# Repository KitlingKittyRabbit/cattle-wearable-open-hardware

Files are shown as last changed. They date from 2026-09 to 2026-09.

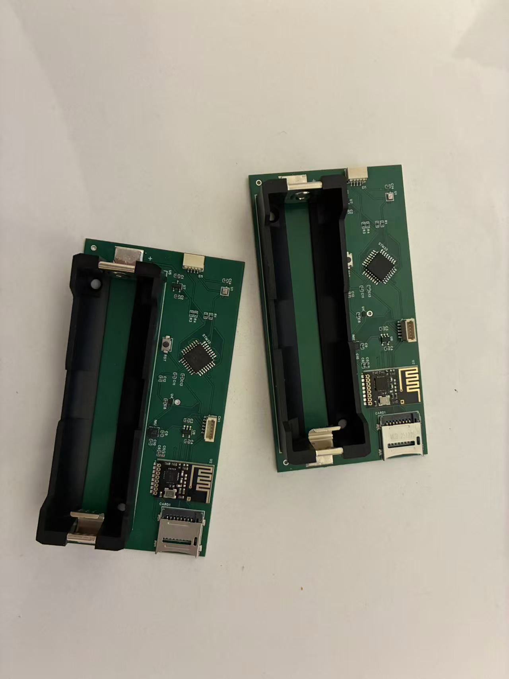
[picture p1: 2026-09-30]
项目文档/图片/实物图.jpg

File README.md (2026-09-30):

# Cattle Wearable Research Platform

An open hardware and firmware prototype for long-duration monitoring of dairy
cows during the transition period. The device combines motion, pressure,
temperature, storage, and low-rate radio telemetry in a belt-mounted enclosure.

This repository documents a research prototype. It does not claim validated
disease prediction, veterinary effectiveness, animal-safety certification, or
production readiness.

## Research scope

The long-term research goal is to investigate whether wearable signals can
support early warning of periparturient disease. Behavior recognition and
respiratory measurements are intermediate capabilities, not established
clinical outcomes. Short farm trials and video alignment are engineering
pretests rather than evidence of diagnostic performance.

## Hardware overview

| Component | Role |
| --- | --- |
| STM32G030K8T6 | Main microcontroller |
| QMI8658A | Six-axis motion sensing |
| GZP pressure sensor | Pneumatic respiratory signal |
| ICP-20100 | Pressure-assisted posture transitions |
| MTS4 | Surface-temperature sensing |
| SD card | Primary sensor-data storage |
| NF-03 radio | Low-rate health heartbeat only |
| OLED | Startup diagnostics only |

The NF-03 link intentionally carries device-health heartbeats rather than the
sensor stream. Full-rate measurements remain on the SD card.

## Repository layout

```text
3D打印模型/        Editable FreeCAD models and STL exports
原理图/            Exported schematic
硬件资料/          Bill of materials
固件/              Bare-metal STM32 firmware and linker script
工具/              Log conversion, radio monitoring, and regression tests
项目文档/          Validation plans and evidence templates
```

Directory names are retained from the original engineering workspace so that
existing build and validation scripts remain traceable.

Slicer project files are intentionally omitted from the public release because
they can embed local printer profiles and account identifiers. Generate a new
print project from the included CAD or STL source for your own printer.

## Firmware build

Install the Arm GNU toolchain and run:

```bash
make -C 固件
```

The output is written to `固件/编译输出/`, which is ignored by Git.

## Data conversion

The current binary log format is V4. Historical V1–V3 frames remain readable.

```bash
python3 工具/bin2csv.py INPUT.bin OUTPUT.csv
```

The logger records timestamp validity, sensor status, storage status, and
sampling diagnostics. A successful conversion does not establish sensor
accuracy; calibration and field validation are separate requirements.

## Radio heartbeat monitor

The 32-byte V3 heartbeat contains a device identifier, sequence number,
monotonic uptime, sensor status, and SD-card status. Each logical heartbeat is
broadcast three times; the receiver records every physical packet and marks
duplicates instead of discarding them.

```bash
python3 工具/nf04_monitor.py
```

Use `--port` to preselect a serial port and `--csv` to choose the append-only
CSV log. Local CSV and JSONL runtime outputs are excluded from Git.

## Validation status

- firmware timing and binary-log parsing have host-side regression tests;
- the CAD enclosure and belt fixtures are included as editable sources;
- the schematic is currently provided as an exported PDF;
- PCB source, manufacturing outputs, and complete assembly instructions are not
  yet included;
- animal fit, durability, battery life, measurement validity, and welfare must
  be evaluated before field deployment.

For detailed historical engineering notes in Chinese, see
[`docs/README.zh-CN.md`](docs/README.zh-CN.md).

## Licensing

- software and firmware: Apache-2.0;
- original mechanical and hardware design files: CERN-OHL-P-2.0;
- original documentation and photographs: CC-BY-4.0.

See [LICENSES.md](LICENSES.md). Component names and third-party specifications
remain the property of their respective owners.

## Animal welfare and safety

Any animal study should receive the approvals required by the relevant
institution and jurisdiction. Independently assess fit, skin contact, pressure,
thermal behavior, battery protection, water ingress, entanglement, and emergency
removal. Do not use this prototype for veterinary decisions without appropriate
validation and professional oversight.

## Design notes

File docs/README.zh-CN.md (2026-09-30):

# 牛腰带 PCB32

奶牛围产期可穿戴监测腰带（PCB32 版本）。

## 研究定位与边界

### 已确认事实

本项目的研究主目标是实现奶牛围产期疾病预警系统，但不保证一定成功。如果目标牛场的病牛样本不足，或者现有数据无法支撑疾病预警，就需要转向备选研究问题；节律研究只是可能方向之一，当前备选路线尚未确定。行为识别是服务于预警的中间能力，不是最终研究目的。

腰带与项圈的主体监测功能相同；腰带相比项圈只多一个气囊，用于呼吸测量。

### 传感器与部件职责（已确认）

| 部件 | 直接职责 |
| --- | --- |
| QMI8658A | 提供运动数据，为行为识别提供输入 |
| GZP | 测量气囊压力变化，目标是获取呼吸信息 |
| ICP-20100 | 辅助识别起卧 |
| MTS4 | 测量体表温度 |
| SD | 保存正式传感器数据 |
| NF-03 | 只发送低频心跳，不发送传感器数据；心跳用于证明设备仍正常工作并提供时间对齐锚点；在满足这两个目的的前提下，发送频率应尽可能低以节省功耗 |
| OLED | 仅用于首次启动后的短时自检，之后不参与正式运行 |

设备的预期生命周期是：首次启动完成自检后进入休眠，等待外部信号唤醒；唤醒后持续采集数据、记录数据并发送低频心跳；此后设备再次重启时不应重新进入首次休眠状态。这里记录的是设计意图，不声称当前固件已经实现上述全部生命周期或时间对齐设计。

牛场短时录像及可能进行的一周试戴属于预实验，用于确认佩戴、对时、连续记录和信号可用性，不是正式疾病预警有效性证据。

### 尚待讨论

以下事项尚未形成既定方案：变量构造、数据基本单位与时间语义、建模方法、具体疾病预警方法、备选研究路线、外部唤醒实现，以及 NF 与 SD/录像的具体对齐实现。

## 项目结构

```
.
├── 3D打印模型/
│   ├── 外壳/          # FreeCAD 外壳模型和指定打印模型
│   ├── 腰带扣合/      # 腰带扣合结构模型
│   └── 打印工程/      # Bambu Studio 打印工程
├── 原理图/            # 原理图 PDF
├── 硬件资料/
│   └── BOM_260530_PCB32_2026-06-09.csv   # 物料清单
├── 固件/              # STM32G030K8T6 裸机固件
│   ├── 源码/          # C 源码
│   ├── 链接脚本/      # 链接脚本
│   ├── 编译输出/      # 本地构建产物，不进入 Git
│   └── *.py / *.sh    # 传感器读取辅助脚本
├── 工具/              # 数据解析与测试脚本
│   ├── bin2csv.py     # 设备 BIN 日志转 CSV
│   ├── nf04_rx.py     # ESP32-C3 + NF-04 接收测试
│   ├── esp32_nf04_rx.ino # ESP32 接收端测试
│   ├── nf04_monitor.py # USB 串口心跳监控面板
│   └── nf04_protocol.py # 心跳编解码与 JSONL 定义
├── 项目文档/
│   ├── 图片/          # 实物照片等文档图片
│   └── 硬件验证/      # 真机验证计划、模板和证据目录
└── 归档/              # 本地历史资料，整体由 Git 忽略
```

## 硬件

- 主控：STM32G030K8T6 (ARM Cortex-M0+)
- IMU：QMI8658A（6 轴加速度/陀螺仪）
- 气压：ICP-20100、GZP 系列
- 温度：MTS4
- 无线：NF-03（2.4 GHz）
- 电源：BH-21700-B1BJ001（21700 电池座）

## 固件编译

```bash
make -C 固件
```

需要安装 ARM GCC 工具链：`arm-none-eabi-gcc`。

## NF-04 心跳与电脑监控

固件在传感器、SD 卡和日志创建完成后立即发送一次启动心跳（seq=0），随后
按运行时绝对 30 分钟网格发送（seq=1、2……），不会从每次发送完成后重新计时。
正式心跳周期固定为 `1800000 ms`（30 分钟）。真机首包和第二包验证、功耗测试
均直接使用这一套正式固件。

NF-04 心跳固定 32 字节，协议版本为 3，字段为：

| 字节 | 含义 |
| --- | --- |
| 0–2 | 构建/部署时配置的设备 ID（大端字节序显示） |
| 3 | 协议版本（V3） |
| 4 | 消息类型（1：心跳） |
| 5–8 | 心跳序号（大端 uint32） |
| 9–12 | 设备单调运行时间 ms（大端 uint32） |
| 13–16 | QMI、ICP、GZP、MTS4 状态 |
| 17 | SD 初始化成功 bit0、正在记录 bit1、SD 已满 bit2 |
| 18–31 | 保留，发送为 0 |

每个 30 分钟逻辑心跳使用同一序号发送三份单向广播：首份立即发送，后两份在
5–15 秒和 15–30 秒窗口内按设备 ID、序号和副本序号确定性分散。每份发送前
重新组装实际运行时间与传感器/SD 状态；不启用自动 ACK 或自动重试。MicroPython
与 Arduino 接收端都监听共同 RF 地址，并把每一份通过协议校验的物理报文逐条输出为稳定的
`NF04_HEARTBEAT {JSON}` 或 `NF04_ERROR {JSON}` 行。电脑端面板启动后可刷新并选择
接收端串口；也可以直接用 `--port` 预选，再运行：

```bash
python3 工具/nf04_monitor.py
# 高级用法：预选串口
python3 工具/nf04_monitor.py --port /dev/ttyACM0 --csv nf04-heartbeats.csv
```

面板按物理接收记录逐行显示在线/超时、电脑接收时间、序号、设备运行时间、四类
传感器状态和 SD/记录状态；同一设备同一序号的三份广播会各占一行，不会覆盖旧记录。
CSV 为每一份通过协议校验的心跳追加一行，并包含 `duplicate` 标记；它不是去重后的
逻辑摘要。面板还在 CSV 同目录追加保存 `nf04-monitor.log` JSONL：每一份实际报文
按电脑接收顺序写入一个 `heartbeat_raw` 事件，完整保留接收时间、设备 ID、协议版本/类型、
序号、运行时间、全部传感器状态、SD 初始化/记录活动/已满状态和 `duplicate: true/false`。
重复标记只用于说明副本关系和序号/统计诊断，不会丢弃、缩减、覆盖或改写任何原始接收记录。
面板中的“清空显示”只清除当前列表和错误提示，不删除、截断或覆盖 CSV/JSONL，清空后仍会
继续接收追加。面板重启或重新连接会继续使用同一文件；这些本机运行输出由 `.gitignore` 排除。
默认超时阈值为 32 分钟；可以用 `--timeout-seconds` 集中调整。未知协议版本、
损坏 JSON、串口断开均显示为错误，不会让面板退出。

启动首包和绝对周期推进由 `固件/源码/issue3_logic.h` 的共享 C 状态机定义，
固件与 `工具/test_issue3_logic.c` 直接复用；电脑端测试只验证协议、记录时间和
面板状态，不复制固件调度算法。

长期集成测试分开报告 SD 时序：正常成功读写模型（5 ms/5 ms）运行 4 小时，
GZP 原始计划 144000 次全部启动并读取，二分后 72000 个结果落盘，真实漏采为 0；
声明的 SD 读/写上界（29 ms/13 ms）
是故障压力边界，不是“采样通过”场景，测试会明确显示其真实漏采数量、重复数和
时间顺序，并验证漏采被计数且采集不会永久停滞。该压力结果不能替代真实 SD 卡长测。

正式采集期间，SD 的读响应/token、512 字节数据块、写响应和 busy 等待使用固件与
主机测试共用的可暂停状态机。SD 与 NF 共用 STM32G030 的 SPI1（PA5/PA6/PA7，AF0）：
SD 识别阶段使用 HSI16/PCLK÷64=250 kHz，完成首个扇区探测后切换到 PCLK÷8=2 MHz；
两条路径均由同一总线所有权和独立 CS 保护。每次最多推进 8 字节，硬件线上 4 us/字节，
连同寄存器轮询和 CS 开销按 8 us/字节设有界上限（单步最多 64 us）。步骤之间先服务
GZP、QMI 和 ICP；启动探测与日志创建发生在正式采集开始前，仍可使用同步初始化路径。
常规 120 ms 扇区写入场景因此要求 GZP 计划、启动、落盘逐点一致且 `missed=0`；
新的 29/13 ms SD 读/写声明上界只作为单独的不可承受压力诊断。
帧保留窗口仍额外保留 1.82 s 的卡内部 busy/元数据安全余量；这不是把旧软件
SPI 吞吐当作新的性能结论。
GZP 转换完成结果使用固定上限的共享小队列跨越短暂 SD/FAT 占用，结果满时才按
实际无法承受的计划网格计为漏采，不通过放宽迟到容限掩盖损失。

正式 BIN 日志当前为 V4：每秒帧大小 368 字节（CRC 位于偏移 364），QMI 槽位 16、
GZP 槽位 5、ICP 槽位 2、MTS4 槽位 1。QMI 仍以约 28.025 Hz 读取并推进原生 FIFO
时钟，GZP 仍按 100 ms 绝对计划网格转换和读取；二者只在成功读取之后由跨 FIFO/转换、
跨帧持久相位各保留连续两个原始项目中的一个；迟到仍在容限内时保留原网格时间，
超出迟到容限而启动当前转换时使用实际启动时间戳。
有意二分不计为 missed、drop、late 或 overflow；真实 I²C、转换、FIFO、队列和时间
窗口故障仍按原诊断报告。`工具/bin2csv.py` 同时保留 V1/V2/V3 历史日志解析。

QMI 运行期的停滞看门狗以“最后一次成功读取完整原始样本”的单调运行时间为唯一期限
基准，而不是只等待某一种 FIFO 状态：初始化后尚未成功读到第一批，或之后连续 500 ms
没有成功原始样本，且 100 ms QMI 服务仍在运行，就触发一次有界恢复。合法空 FIFO、
count/`FIFO_STATUS` 矛盾、非空 FIFO 的 CTRL9/FIFO_DATA/cleanup 失败都会留在这条
无成功样本计时路径；单次瞬态错误不会立即重复重置。恢复退出读模式、RST_FIFO、重写并
读回当前 CTRL1/2/3/6/7/8、水位和 FIFO_CTRL，再独立读回 count LSB/status，核验 count=0、
`NOT_EMPTY/WTM/FULL/OVERFLOW` 全部清零及 `FIFO_RD_MODE=0`，失败后至少 1 s 才重试。
每次停滞恢复尝试写入 V4 状态位 10（兼容旧名称 `qmi_empty_recovery`），成功/失败分别
按事件累计 OR 写入位 11/12；无论寄存器恢复成败，旧 QMI 时钟都会失效，下一批成功原始
样本按当前时间重新锚定。`bin2csv.py` 输出这三个可读状态列，历史 V1/V2/V3 帧按零值
兼容解析。

即使 FIFO_DATA 每次都成功，运行期每个合法非空批次仍会用
`batch_now_us - (samples - 1) * ISSUE3_QMI_SAMPLE_PERIOD_US` 计算当前采样窗口；若旧软件
时钟落后该窗口超过 500 ms，则在读取样本前前移重锚并保留 `qmi_reanchors`/重新锚定状态。
小于该阈值的 100 ms 调度抖动继续沿用原时钟，不会每批重锚；批次锚点保证最后一个样本时间
不晚于本次读取时刻且输出时间单调。该校正独立于“500 ms 无成功原始样本”恢复看门狗。

QMI 的正式 FIFO 服务在确认有合法完整样本后直接进入读模式，逐个读取整个批次；某个
保留样本若落到 TIME、SD-owned OWNER 或 QUEUE 阻塞，只丢弃并记录该样本，不能拒绝
同批次后续样本，也不会因此复位 FIFO 或重新锚定。GZP 服务轻微迟到时仍启动当前网格
点；若已经越过多个网格，则只把已经完整错过的历史点计为 missed，最多启动一个当前
转换，并在超过迟到容限时用实际启动时间作为结果时间戳，下一截止点仍回到未来的绝对
100 ms 网格，不背靠背补做历史转换。

### 实机 SD 瓶颈定位诊断（本轮新增）

正式固件包含一个只驻留 RAM、不会写入 SD 或发送到 NF 的诊断区：
`volatile Issue3RuntimeDiagnostics r_issue3_diag`。正式运行开始后其首字段应为
`magic=0x49534433`、`version=1`；启动探测不会混入计数。结构记录主循环和
`sd_async_step()` 进度、同一活动事务内相邻 step 的最大间隔、扇区完成间隔、持久化字节和完整帧数、帧队列与
GZP 结果队列峰值、QMI/GZP/ICP 接收与入帧数，以及按队列/时间窗口/物理槽所有权
分类的丢弃数。

`sd_step_max_gap_ms` 只在同一尚未结束的 SD 事务中比较相邻两次
`sd_async_step()`；事务完成后会清除活动身份，因此两个独立事务之间的正常空闲不会
污染该字段。事务、step、阶段、扇区完成、FAT 预取/簇链接/metadata 和 TIME/OWNER/QUEUE
丢弃分类均通过 `固件/源码/issue3_logic.h` 的共享状态入口更新，主机诊断测试与正式
`main.c` 使用同一转换逻辑。

帧丢弃分类来自实际 frame-open 结果：TIME 表示时间戳早于可恢复窗口或落入不可恢复
时间孔洞，OWNER 仅表示该时间戳实际命中的物理槽由 SD pending 持有，QUEUE 表示需要
新开/补开帧但容量或其他队列条件阻塞；不会再以“存在任意 pending 槽”推断 OWNER。

SD 部分包括读/写/总事务数、每个完整事务的最近/累计/最大耗时、SPI 传输字节、
read-token 与 write-busy 轮询总数和单事务最大值、SPI 超时次数。`sd_transaction`
及 `sd_phase[0..6]` 的元素均为 `{entries,total_ms,last_ms,max_ms}`；阶段索引为：
`0 CMD`、`1 响应`、`2 读 token/写 token`、`3 读数据/读 CRC`、`4 写数据/写 CRC`、
`5 写响应`、`6 write-busy`。`total_ms` 为饱和的 32 位累计值，单次 `last_ms`/`max_ms`
为饱和的 16 位毫秒值（超过 65535 ms 会保留为 0xffff）。`fat_prefetch`、
`fat_link`、`metadata` 使用相同的四字段结构，分别对应 FAT 预取/分配、簇链接和
目录元数据逻辑操作。

Tiger 可在运行约两分钟后通过 ST-Link/GDB 一次读取完整结构（端口按现场 OpenOCD
配置替换）：

```text
arm-none-eabi-gdb 固件/编译输出/firmware.elf
(gdb) target extended-remote :4242
(gdb) monitor halt
(gdb) set print pretty on
(gdb) p/x r_issue3_diag
```

本诊断提交只用于区分 SPI 传输、卡 token/busy、FAT/元数据和前台推进间隔造成的
瓶颈，不表示吞吐问题已经修复；读取后请保留 magic/version 及全部字段原样记录。

正式主循环不会在每个 8 字节步骤后无条件执行 WFI：只要 SD/FAT、FIFO、待提交帧或
转换结果有可立即推进的工作，就继续服务传感器并推进下一步。QMI 保留 PB6/EXTI
快速路径，同时由 TIM3 每 100 ms 置独立的 FIFO/status 轮询标志；即使水位边沿漏掉，
仍会读取真实 FIFO level/status 并复用完整批次逐样本读取、溢出恢复和重新锚定逻辑。ICP 没有
中断线，由另一个独立的 100 ms 标志限频服务；SD 每个 8 字节步骤前先服务 QMI，再
服务到期 ICP，I²C 失败由下一轮继续重试，不把传感器停采变成前台忙轮询。GZP 约
20 ms、MTS4 约 50 ms 的转换完成期限使用 TIM3 比较唤醒；100 ms 更新中断负责较长期限，因此
WFI 不会把短转换拖到下一个 100 ms。日志还以完整数据扇区的实际完成时间作为进度
心跳；超过一个帧保留窗口加 5 秒仍有待写入工作却没有进度时，`log_active` 会清零，
避免心跳继续把写入停滞报告为正常记录。

主循环睡眠入口使用 `issue3_runtime_sleep_entry()`：先在关中断（PRIMASK）状态下重新
读取全部前台工作、软件到期标志和 TIM3/QMI 硬件 pending 位，再配置比较唤醒，执行
DSB/WFI，最后恢复中断。NF 的运行期短等待另使用同语义的
`issue3_atomic_wait_begin()`/`issue3_atomic_wait_step()`：新等待在同一关中断区内
关闭旧 CC1IE、清除上一轮 CC1IF、清零完成标志、读取 CNT、设置新的 CCR1 并启用
CC1IE；若配置期间计数跨过目标，则从新 CNT 重新建立目标。随后再在关中断后检查
`r_short_timer_done` 和 TIM3 pending，因此旧 pending 不会替代本次延迟，新事件仍会
保持 pending 并唤醒 WFI。Cortex-M0+ 在 PRIMASK 期间到达的 TIM3 比较、TIM3 更新或
QMI EXTI 会保持 pending 并唤醒 WFI，随后由 ISR 处理；比较配置不会清除刚到达的
pending 标志。`工具/test_issue3_logic.c` 和四小时异步测试直接调用共享入口，覆盖主
循环三种竞态、旧 CC1IF、计数回绕和配置前进，避免用独立的理想睡眠模型替代固件路径。

异步生产路径的四小时离散事件回归位于
`工具/test_issue3_async_long_capture.c`。它直接驱动 `Issue3SdTransfer`、
`Issue3SpiBus`、帧队列、QMI 逐样本 FIFO 服务、GZP/ICP 调度和 `Issue3LogPrefetch`，模拟
约 28.025 Hz QMI 原始读取、10 Hz GZP 原始转换、2 Hz ICP、30 分钟 MTS4、QMI EXTI 永不触发时的
100 ms 轮询兜底、ICP 100 ms 限频服务和非零 I²C 时间成本、V4 368 字节帧跨扇区和 FAT
跨簇链。运行期簇分配和旧簇到新簇的链接也逐步通过异步 FAT0/FAT1 扇区读写完成；
同步 FAT 访问只用于启动初始化和结束时的测试清理。SD 命令、token、数据和 busy
阶段之间继续推进传感器与 NF。测试以离散时间
运行四小时而不是等待现实四小时，最后从模拟卡的目录有效长度、FAT0/FAT1 链和实际
扇区字节反解析帧、CRC、样本唯一性和三副本心跳。主机上可用以下命令运行：

```bash
cc -std=c11 -O2 -Wall -Wextra -Werror -I固件/源码 \
  工具/test_issue3_async_long_capture.c -o /tmp/test_issue3_async_long_capture
/tmp/test_issue3_async_long_capture
```

NF-03 与 SD 共用硬件 SPI1 线，运行期由共用 C 所有权状态机互斥：SD 从命令开始直到
响应、数据、busy 完成并释放 CS 前，NF 只保留待发送副本，不访问 SPI；NF 发送、唤醒
和休眠期间也不会启动新的 SD 事务。心跳副本在总线释放后继续使用原序号和实际发送时刻
重新组包。主机回归覆盖 SD 命令、读 token、写数据和写 busy 阶段的到期心跳，并检查两
个 CS 从不同时有效。正常 120 ms 分步 SD 集成还持续产生 ICP 2 Hz 样本，样本经过 FIFO、
帧队列和模拟 SD 字节后按时间戳反解析，要求输入与落盘一一对应、无重复和漏采。

## 协作说明

- 本项目为私有仓库，仅供团队内部协作。
- 大文件（规格书 PDF、PPT、原始论文等）已归档到本地 `归档/`，不在 Git 中跟踪。
- 新增硬件资料请放到对应子目录；临时/个人文件不要提交。

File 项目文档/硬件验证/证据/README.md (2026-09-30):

# Validation evidence

This directory is reserved for small, reviewable hardware-test evidence, such
as:

- a short SD-card data sample used to validate `工具/bin2csv.py`;
- a short NF-03 receiver log demonstrating a physical radio packet;
- a necessary screenshot or compact text summary.

No physical-test sample or receiver log is included in the initial public
release. Add evidence only after a manual hardware test, and record its source,
date, firmware commit, and intended use in the corresponding validation record.

Do not commit long experiments, complete SD-card exports, private farm or animal
data, or large radio logs. Every evidence file must have a clear provenance and
data-sharing permission.

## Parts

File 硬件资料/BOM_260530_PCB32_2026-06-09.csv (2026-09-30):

No. | Quantity | Comment | Designator | Footprint | Value | Manufacturer Part | Manufacturer | Supplier Part | Supplier
1 | 4 | 1uF | C1,C2,C3,C4 | C0402 | 1uF | CL05A105KA5NQNC | SAMSUNG(三星) | C52923 | LCSC
2 | 2 | 10uF | C5,C12 | C0402 | 10uF | CL05A106MQ5NUNC | SAMSUNG(三星) | C15525 | LCSC
3 | 7 | 100nF | C6,C8,C9,C10,C11,C13,C14 | C0402 | 100nF | CL05B104KO5NNNC | SAMSUNG(三星) | C1525 | LCSC
4 | 1 | 472192001 | CARD1 | TF-SMD_472192001 |  | 472192001 | MOLEX | C164170 | LCSC
5 | 1 | ZX-SH1.0-5PLT | CN1 | CONN-SMD_5P-P1.00_ZX-SH1.0-5PLT |  | ZX-SH1.0-5PLT | Megastar(兆星) | C7430454 | LCSC
6 | 1 | QMI8658A | IMU | LGA-14_L3.0-W2.5-P0.50-TL |  | QMI8658A | QST(上海矽睿) | C3021082 | LCSC
7 | 2 | 10kΩ | R1,R2 | R0402 | 10kΩ | 0402WGF1002TCE | UNI-ROYAL(厚声) | C25744 | LCSC
8 | 2 | 1MΩ | R3,R4 | R0402 | 1MΩ | FRC0402J105 TS | FOJAN(富捷) | C2906900 | LCSC
9 | 1 | TS-1088-AC02016 | RST | SW-SMD_L4.0-W2.9-LS5.0-A |  | TS-1088-AC02016 | XUNPU(讯普) | C720475 | LCSC
10 | 1 | STM32G030K8T6 | STM32 | LQFP-32_L7.0-W7.0-P0.80-LS9.0-BL |  | STM32G030K8T6 | ST(意法半导体) | C431631 | LCSC
11 | 1 | ICP-20100 | U1 | LGA-10_L2.0-W2.0-P0.50-TL_ICP-20100 |  | ICP-20100 | TDK InvenSense(应美盛) | C5343527 | LCSC
12 | 1 | 2.4GHz | U2 | WIRELM-SMD_AI-THINKER_NF-03 | 2.4GHz | NF-03 | Ai-Thinker(安信可) | C115101 | LCSC
13 | 1 | ZX-SH1.0-4PWT | U3 | CONN-SMD_4P-P1.00_MEGASTAR_ZX-SH1.0-4PWT |  | ZX-SH1.0-4PWT | Megastar(兆星) | C7430446 | LCSC
14 | 1 | MTS4 | U4 | DFN-4_L1.6-W1.2-P0.60-TL-EP0.8 |  | MTS4 | Mysentech(敏源传感) | C18723626 | LCSC
15 | 1 | BH-21700-B1BJ001 | U5 | BAT-SMD_L82.5.5-W25-BH-21700-B1BJ001 |  | BH-21700-B1BJ001 | MYOUNG(美阳) | C20606791 | LCSC
16 | 1 | SGM2554AYN5G/TR | U6 | SOT-23-5_L3.0-W1.7-P0.95-LS2.8-BR |  | SGM2554AYN5G/TR | SGMICRO(圣邦微) | C183309 | LCSC
17 | 1 | ME6211A33M3G-N | U7 | SOT-23-3_L2.9-W1.6-P1.90-LS2.8-BR |  | ME6211A33M3G-N | MICRONE(南京微盟) | C168807 | LCSC

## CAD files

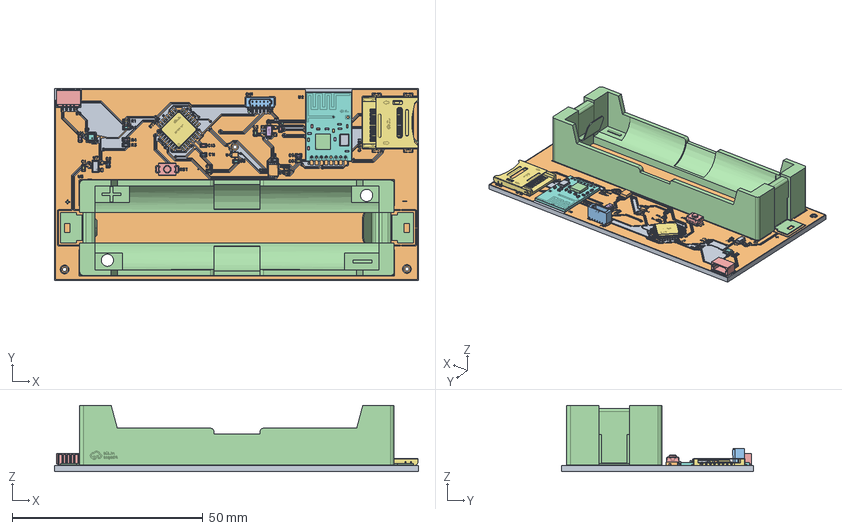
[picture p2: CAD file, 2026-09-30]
3D打印模型/外壳/主板.FCStd
95.5 x 50.4 x 17.4 mm
Board~UACb
TopCopper~UACb
BottomCopper~UACb
TopSilkscreen~UACb
SW-SMD_L4.0-W2.9-LS5.0-A~SW-SMD_L4.0-W2.9-LS5.0-A~UACb
R0402~R0402_L1.0-W0.5-H0.4~UACb
R0402~R0402_L1.0-W0.5-H0.4~UACb001
R0402~R0402_L1.0-W0.5-H0.4~UACb002
R0402~R0402_L1.0-W0.5-H0.4~UACb003
DFN-4_L1.6-W1.2-P0.60-TL-EP0.8~DFN-4_L1.6-W1.2-P0.60-TL-EP0.8~UACb
C0402~C0402_L1.0-W0.5-H0.5~UACb
C0402~C0402_L1.0-W0.5-H0.5~UACb001
C0402~C0402_L1.0-W0.5-H0.5~UACb002
C0402~C0402_L1.0-W0.5-H0.5~UACb003
C0402~C0402_L1.0-W0.5-H0.5~UACb004
C0402~C0402_L1.0-W0.5-H0.5~UACb005
C0402~C0402_L1.0-W0.5-H0.5~UACb006
C0402~C0402_L1.0-W0.5-H0.5~UACb007
C0402~C0402_L1.0-W0.5-H0.5~UACb008
C0402~C0402_L1.0-W0.5-H0.5~UACb009
C0402~C0402_L1.0-W0.5-H0.5~UACb010
C0402~C0402_L1.0-W0.5-H0.5~UACb011
C0402~C0402_L1.0-W0.5-H0.5~UACb012
LGA-10_L2.0-W2.0-P0.50-TL_ICP-20100~LGA-10_L2.0-W2.0-P0.50-TL_ICP-20100~UACb
SOT-23-3_L2.9-W1.6-P1.90-LS2.8-BR~SOT-23-3L_L2.9-W1.6-H1.1-LS2.8-P0.95~UACb
LGA-14_L3.0-W2.5-P0.50-TL~LGA-14_L2.5-W3.0-H0.9-P0.50~UACb
CONN-SMD_5P-P1.00_ZX-SH1.0-5PLT~CONN-SMD_5P-P1.00_ZX-SH1.0-5PLT~UACb
BAT-SMD_L82.5.5-W25-BH-21700-B1BJ001~BAT-SMD_L82.5-W25-BH-21700-B1BJ001~UACb
CONN-SMD_4P-P1.00_MEGASTAR_ZX-SH1.0-4PWT~CONN-SMD_4P-P1.00_MEGASTAR_ZX-SH1.0-4PWT~UACb
SOT-23-5_L3.0-W1.7-P0.95-LS2.8-BR~SOT-23-5_L2.9-W1.6-H1.1-LS2.8-P0.95~UACb
TF-SMD_472192001~TF-SMD_472192001~UACb
WIRELM-SMD_AI-THINKER_NF-03~WIRELM-SMD_AI-THINKER_NF-03~UACb
WIRELM-SMD_AI-THINKER_NF-03~WIRELM-SMD_AI-THINKER_NF-03~UACb001
WIRELM-SMD_AI-THINKER_NF-03~WIRELM-SMD_AI-THINKER_NF-03~UACb002
WIRELM-SMD_AI-THINKER_NF-03~WIRELM-SMD_AI-THINKER_NF-03~UACb003
WIRELM-SMD_AI-THINKER_NF-03~WIRELM-SMD_AI-THINKER_NF-03~UACb004
WIRELM-SMD_AI-THINKER_NF-03~WIRELM-SMD_AI-THINKER_NF-03~UACb005
WIRELM-SMD_AI-THINKER_NF-03~WIRELM-SMD_AI-THINKER_NF-03~UACb006
WIRELM-SMD_AI-THINKER_NF-03~WIRELM-SMD_AI-THINKER_NF-03~UACb007
WIRELM-SMD_AI-THINKER_NF-03~WIRELM-SMD_AI-THINKER_NF-03~UACb008
WIRELM-SMD_AI-THINKER_NF-03~WIRELM-SMD_AI-THINKER_NF-03~UACb009
WIRELM-SMD_AI-THINKER_NF-03~WIRELM-SMD_AI-THINKER_NF-03~UACb010
WIRELM-SMD_AI-THINKER_NF-03~WIRELM-SMD_AI-THINKER_NF-03~UACb011
WIRELM-SMD_AI-THINKER_NF-03~WIRELM-SMD_AI-THINKER_NF-03~UACb012
WIRELM-SMD_AI-THINKER_NF-03~WIRELM-SMD_AI-THINKER_NF-03~UACb013
WIRELM-SMD_AI-THINKER_NF-03~WIRELM-SMD_AI-THINKER_NF-03~UACb014
LQFP-32_L7.0-W7.0-P0.80-LS9.0-BL~LQFP-32_L7.0-W7.0-H1.4-LS9.0-P0.80~UACb

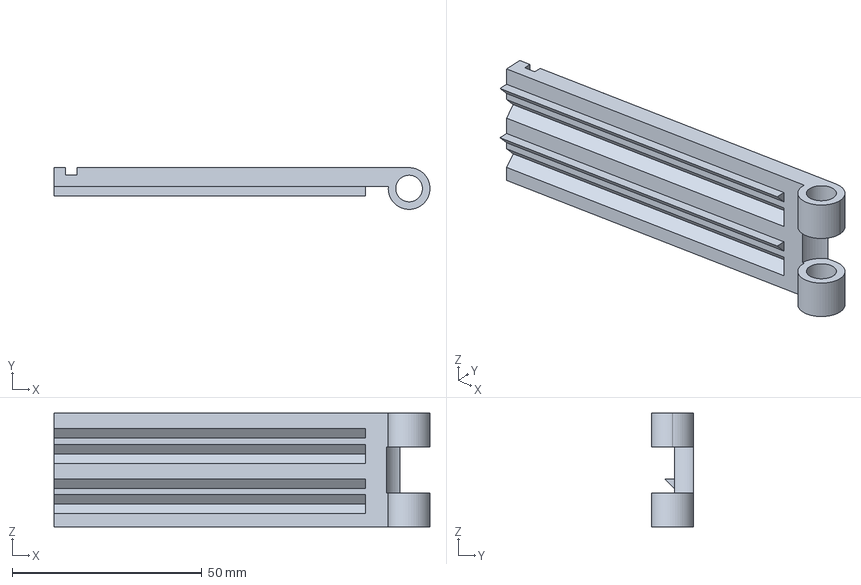
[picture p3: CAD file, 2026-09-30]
3D打印模型/腰带扣合/上夹板.FCStd
99.0 x 11.0 x 30.0 mm

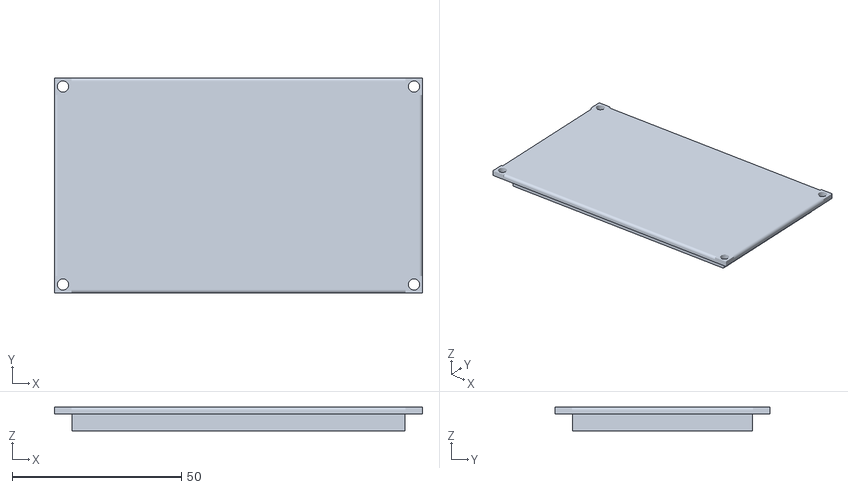
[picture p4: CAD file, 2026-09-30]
3D打印模型/外壳/上盖-BodyPad002.stl
108.6 x 63.4 x 7.00

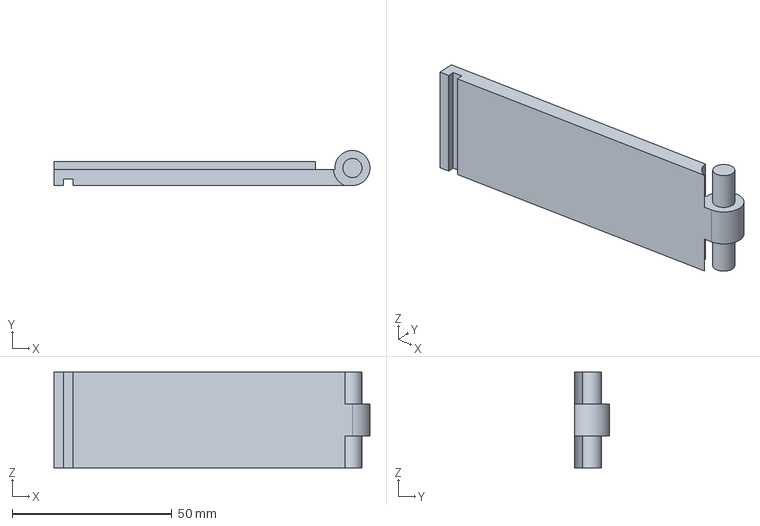
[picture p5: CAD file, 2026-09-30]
3D打印模型/腰带扣合/下夹板.FCStd
99.0 x 11.0 x 30.0 mm

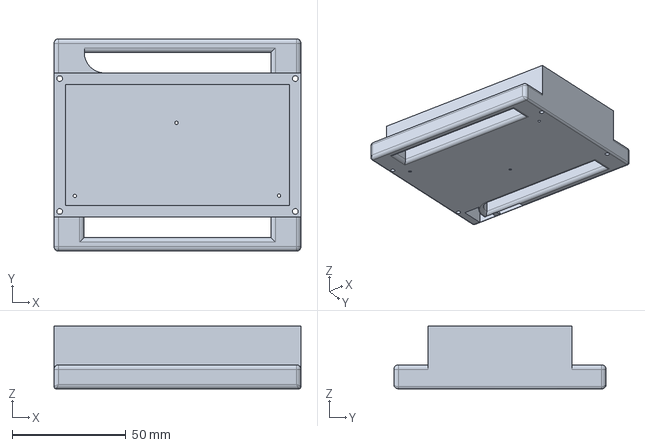
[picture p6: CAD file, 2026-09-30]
3D打印模型/外壳/外壳_已修复.FCStd
108.6 x 93.4 x 27.6 mm

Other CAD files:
3D打印模型/腰带扣合/组装.FCStd
3D打印模型/外壳/上盖.FCStd

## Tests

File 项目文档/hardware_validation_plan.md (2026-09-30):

# PCB32 真机验证计划

## 1. 目的与范围

本计划用于验证当前 STM32G030K8T6 固件在已经完成基础 bring-up 的 PCB32 硬件上的回归行为。重点是确认固件修改没有破坏原有的启动、传感器采集、SD 存储、NF-03 通信和 Reset 恢复流程。

本计划不重复短路检查、器件方向检查、限流上电、焊接检查等新板首次 bring-up 项目，也不覆盖功耗、续航和低功耗待机。

当前可用测试条件：可烧录和 Reset，有 OLED 和 SD 卡；有 NF-03 接收端时可做真实无线收包；有普通万用表；不依赖示波器或逻辑分析仪。

## 2. 测试前记录

开始测试前，先复制 `项目文档/硬件验证/TEMPLATE.md`，按命名规则保存为：

```text
项目文档/硬件验证/<嘉立创订单编号>_<YYYYMMDD>.md
```

记录以下信息：

- 嘉立创订单编号。无法区分同一订单中的单板时，不虚构板号。
- PCB revision / 硬件版本；没有明确标识时填写 `未知`。
- 固件 Git commit SHA。
- 测试日期和操作者。
- 供电方式、电池或外部电源信息。
- SD 卡容量、品牌和文件系统信息。
- NF-03 接收端是否可用。

测试前确认固件构建成功，并将实际烧录的 commit SHA 填入记录。测试过程中的每个项目必须填写 `PASS`、`FAIL` 或 `NOT TESTED`，并记录观察到的数值和现象。

## 3. 启动流程

1. 烧录待验证固件并 Reset 或重新上电。
2. 观察 OLED 启动自检，记录 QMI8658A、GZP、ICP-20100、MTS4、SD、NF-03 的状态和显示值。
3. 确认自检有结束点，不会永久停留在启动测试界面。
4. 确认设备无需人工操作即可进入正常采集流程。
5. 确认有 SD 卡时进入存储流程，有 NF-03 初始化成功时进入发送流程。

判定：各模块状态可观察、自检结束并进入正常工作流程为 `PASS`。自检永久阻塞、关键状态无法显示或设备未进入采集/存储/发送流程为 `FAIL`。

说明：`OK/FAIL` 只表示固件是否完成有效读取或初始化，不自动判定测量值的物理正确性。传感器数值是否合理由现场观察记录单独判断。

## 4. 传感器回归

### 4.1 QMI8658A

1. 设备进入正常采集后，记录 OLED 上的三轴加速度和三轴陀螺仪读数。
2. 静止观察一段时间，再移动和旋转 PCB。
3. 记录读数是否持续更新，以及动作是否引起可重复观察的变化。

读数持续存在且移动、旋转与读数变化有可观察关联为 `PASS`。读数缺失、长期不变、明显异常或动作与读数无关联为 `FAIL`。

### 4.2 GZP

1. 连接实际使用的气囊。
2. 压缩并释放气囊多次。
3. 记录 OLED 上的压力读数和变化方向、幅度等现象。

压力读数持续存在，并对压缩和释放产生明显对应变化为 `PASS`；否则为 `FAIL`。

### 4.3 ICP-20100

1. 记录持续压力和温度读数。
2. 在条件允许时改变高度或施加明显压力变化。
3. 记录读数是否出现相应变化。

能够持续取得读数，且动作与读数存在可观察关联为 `PASS`；否则为 `FAIL`。

### 4.4 MTS4

1. 记录静置时温度读数。
2. 用手接触或捂热传感器一段时间。
3. 松开后继续观察，记录温度变化。

读数处于现场认为合理的范围，并对接触或捂热产生可观察变化为 `PASS`；否则为 `FAIL`。

## 5. SD 卡

### 5.1 SD 持续存储

1. 正式采集开始后确认 SD 卡产生新的记录文件。
2. 运行一段时间后再次确认文件大小或记录内容持续增长。

只要记录文件产生并持续增长，SD 持续存储即为 `PASS`；没有新记录、只写入一次后停止或写入失败为 `FAIL`。未执行该项时填写 `NOT TESTED`。

### 5.2 SD 数据解析

1. 停止测试后取出 SD 卡，取得一小段实际产生的数据。
2. 使用仓库现有 `工具/bin2csv.py` 尝试解析该样本。
3. 将足以证明解析链路正常的小型样本保存到 `项目文档/硬件验证/证据/`，不要提交长时间实验产生的原始数据。

小型样本由当前解析工具正确解析为 `PASS`；样本无法解析或解析结果不正确为 `FAIL`；未执行该项时填写 `NOT TESTED`。该结果只评价主机端解析链路，不反向改变 SD 持续存储结果。SD 文件正常产生并持续增长、但解析失败时，应记录 SD 持续存储为 `PASS`、SD 数据解析为 `FAIL`，并在异常中记录解析失败现象。

## 6. NF-03

### 6.1 开机本地自检

记录 OLED 上 NF-03 的启动状态。该项只确认 STM32 与 NF-03 之间的 SPI 寄存器读写和初始化，不依赖外部接收端。

本地寄存器读写和初始化成功为 `PASS`，失败为 `FAIL`。

### 6.2 真实无线收包

有可用接收端时：

1. 启动接收端并记录接收端程序、配置和开始时间。
2. 让腰带运行正常采集和发送流程。
3. 确认接收端收到预期测试数据，并记录数据包数量、时间范围或关键字段。
4. 将小型接收日志保存到 `项目文档/硬件验证/证据/`。

收到了预期数据为 `PASS`；已执行但没有收到预期数据为 `FAIL`。

没有接收端时，真实无线收包项填写 `NOT TESTED`，不能用开机自检结果替代真实链路验证。

## 7. Reset 回归

1. 设备进入正常采集后手动 Reset 多次，建议至少记录 3 次；实际次数填写在验证记录中。
2. 每次观察启动自检、自检结束、采集恢复、SD 恢复和 NF-03 恢复情况。
3. 记录任何偶发启动失败、外设不恢复或传感器状态异常。

每次 Reset 后都能完成启动并恢复正常采集、存储和发送流程为 `PASS`。任一次失败都将该项判为 `FAIL`，并记录失败次数和现象；未执行则为 `NOT TESTED`。

## 8. 结果与证据留档

每次测试保存一份记录到 `项目文档/硬件验证/`，使用 `TEMPLATE.md` 的字段。记录必须包含：

- 每个项目的 `PASS` / `FAIL` / `NOT TESTED`。
- 关键实际观察值和现象。
- 异常、偶发问题和未完成项目。
- 小型 SD 样本、NF 接收日志或其他证据的仓库路径。

长期实验原始数据、完整 SD 卡导出和过大的无线日志不提交到 Git。小型、脱敏、可复现检查所需的证据可以放在 `项目文档/硬件验证/证据/`，并在记录中注明用途。

## 9. Acceptance Criteria 对照

本计划完成以下 Issue #4 要求：

- 提供一套明确、可重复执行的真机回归验证步骤。
- 测试条件与当前设备一致，不要求示波器或逻辑分析仪。
- 明确这是已有硬件上的固件回归，不重复新板基础 bring-up。
- 覆盖启动、QMI8658A、GZP、ICP-20100、MTS4、SD、NF-03 和 Reset 回归。
- 每个项目均使用 `PASS`、`FAIL` 或 `NOT TESTED`，并记录实际观察值和现象。
- 使用嘉立创订单编号作为 PCB/SMT 批次追溯标识；无法区分同一订单中的单板时不虚构板号。
- 提供 `项目文档/硬件验证/TEMPLATE.md` 作为验证记录模板。
- 预留 `项目文档/硬件验证/证据/` 保存小型 SD 样本和 NF 接收日志；长期原始数据不提交。
- 将功耗、续航和低功耗待机明确排除在本计划之外。

仓库中的验证计划和模板不代表任何一次真机测试已经完成。首份实际记录必须在人工烧录、操作和观察硬件后填写；在此之前不得将任何项目填写为已验证的 `PASS`。

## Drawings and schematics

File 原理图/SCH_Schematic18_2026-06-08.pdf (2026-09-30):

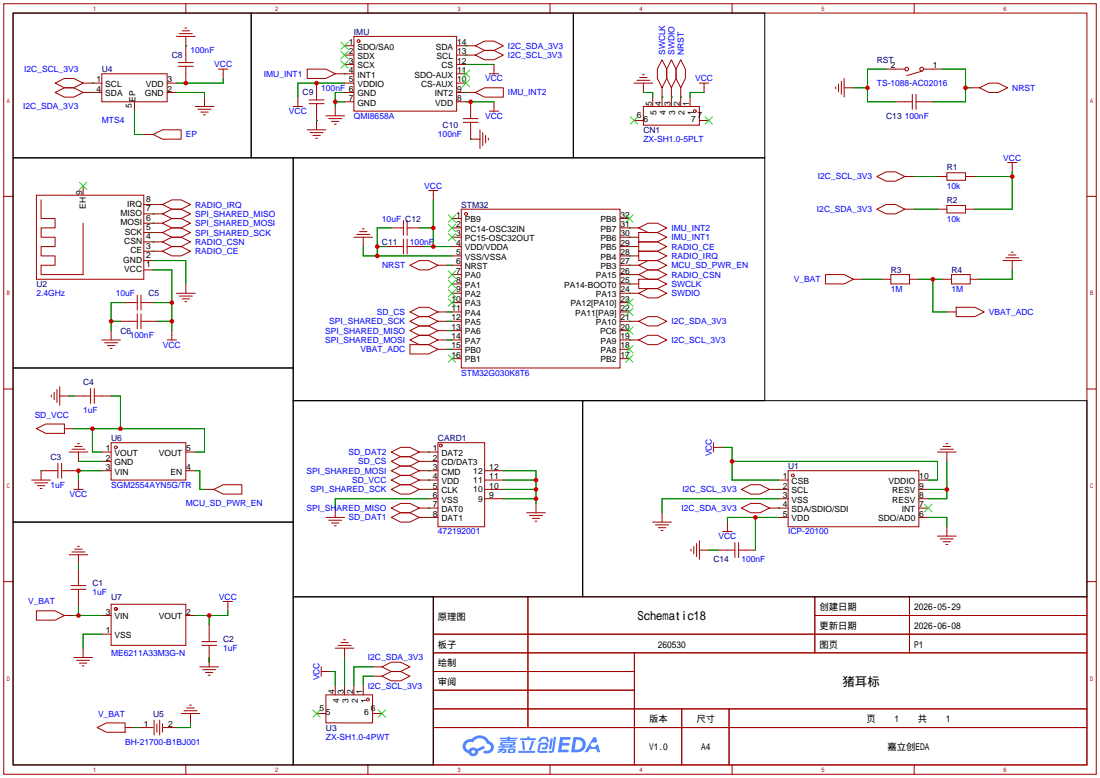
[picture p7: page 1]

ZX-SH1.0-5PLT SWCLK SWDIO NRST

CS-AUX 10 SDO-AUX 11 CS 12 SCL 13 SDA 14

原理图 | Schematic18 | 创建日期 | 2026-05-29

更新日期 | 2026-06-08

绘制 | | 猪耳标
审阅

V1.0 | A4 | 嘉立创EDA

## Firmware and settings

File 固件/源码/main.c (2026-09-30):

#include <stdint.h>
#include "stm32g030.h"
#include "issue3_logic.h"

extern uint32_t _estack;
extern uint32_t _sdata;
extern uint32_t _edata;
extern uint32_t _sbss;
extern uint32_t _ebss;
extern uint32_t _etext;

void Reset_Handler(void);
void Default_Handler(void);
void NMI_Handler(void) __attribute__((weak, alias("Default_Handler")));
void HardFault_Handler(void) __attribute__((weak, alias("Default_Handler")));
void SVC_Handler(void) __attribute__((weak, alias("Default_Handler")));
void PendSV_Handler(void) __attribute__((weak, alias("Default_Handler")));
void SysTick_Handler(void);
void EXTI4_15_IRQHandler(void);
void TIM3_IRQHandler(void);

__attribute__((section(".isr_vector")))
void (*const vector_table[])(void) = {
    (void (*)(void))&_estack,
    Reset_Handler,
    NMI_Handler,
    HardFault_Handler,
    0, 0, 0, 0, 0, 0, 0,
    SVC_Handler,
    0, 0,
    PendSV_Handler,
    SysTick_Handler,
    /* External IRQ 0..7: WWDG..EXTI4_15. */
    0, 0, 0, 0, 0, 0, 0, EXTI4_15_IRQHandler,
    /* External IRQ 8..14: DMA..TIM2. */
    0, 0, 0, 0, 0, 0, 0,
    /* External IRQ 15: TIM2.  IRQ16 is TIM3 on STM32G030. */
    0,
    TIM3_IRQHandler,
    /* Remaining STM32G0 IRQ slots. */
    0, 0, 0, 0, 0, 0, 0, 0, 0, 0, 0, 0, 0, 0, 0, 0
};

typedef struct {
    volatile uint32_t CR1;
    volatile uint32_t CR2;
    volatile uint32_t OAR1;
    volatile uint32_t OAR2;
    volatile uint32_t TIMINGR;
    volatile uint32_t TIMEOUTR;
    volatile uint32_t ISR;
    volatile uint32_t ICR;
    volatile uint32_t PECR;
    volatile uint32_t RXDR;
    volatile uint32_t TXDR;
} I2C_TypeDef;

#define I2C1   ((I2C_TypeDef *)I2C1_BASE)

#define RCC_APBENR1_I2C1EN  (1U << 21)
#define RCC_APBRSTR1_I2C1RST (1U << 21)
#define RCC_CCIPR_I2C1SEL_Msk (3U << 12)
#define RCC_CCIPR_I2C1SEL_HSI16 (2U << 12)

#define I2C_ISR_TXE   (1U << 0)
#define I2C_ISR_TXIS  (1U << 1)
#define I2C_ISR_RXNE  (1U << 2)
#define I2C_ISR_NACKF (1U << 4)
#define I2C_ISR_STOPF (1U << 5)
#define I2C_ISR_TC    (1U << 6)
#define I2C_CR1_PE    (1U << 0)
#define I2C_CR2_START (1U << 13)
#define I2C_CR2_STOP  (1U << 14)
#define I2C_CR2_RD_WRN (1U << 10)
#define I2C_ICR_NACKCF  (1U << 4)
#define I2C_ICR_STOPCF  (1U << 5)

#define I2C_SCL_PIN (1U << 9)
#define I2C_SDA_PIN (1U << 10)

#define SD_CS_PIN   (1U << 4)
#define SD_SCK_PIN  (1U << 5)
#define SD_MISO_PIN (1U << 6)
#define SD_MOSI_PIN (1U << 7)
#define SD_PWR_PIN  (1U << 3)

#define NF_CS_PIN   (1U << 15)
#define NF_CE_PIN   (1U << 5)
#define NF_IRQ_PIN  (1U << 4)

#define OLED_SDA_PIN (1U << 13)
#define OLED_SCL_PIN (1U << 14)
#define OLED_ADDR_WRITE 0x78U
#define OLED_COLUMN_OFFSET 2U

#define USART_CR1_UE    (1U << 0)
#define USART_CR1_TE    (1U << 3)
#define USART_CR1_RE    (1U << 2)
#define USART_ISR_TXE   (1U << 7)
#define USART_ISR_TC    (1U << 6)

static volatile uint32_t r_magic;
static volatile uint32_t r_i2c_scan0, r_i2c_scan1, r_i2c_scan2, r_i2c_scan3;
static volatile uint32_t r_i2c_last_isr, r_i2c_last_cr2;
static volatile uint8_t r_i2c_last_addr;
static volatile int16_t r_ax, r_ay, r_az, r_gx, r_gy, r_gz;
static volatile int16_t r_mts4_temp;
static volatile uint8_t r_qmi_ok, r_mts4_ok, r_icp_ok;
static volatile uint8_t r_sd_ok, r_sd_init_ok, r_sd_cmd0, r_sd_cmd8, r_sd_acmd41, r_sd_cmd58;
static volatile uint32_t r_sd_ocr;
static volatile uint8_t r_spi_timeout;
/* Keep only the first eight bytes of the read-sector diagnostic; the full
 * sector is consumed transiently and is not needed after probing. */
static volatile uint8_t r_sd_read0, r_sd_sector0[8];
static volatile uint16_t r_sd_mbr_sig;
static volatile uint8_t r_log_ok;
static volatile uint16_t r_log_bytes;
static volatile uint32_t r_log_cluster;
static volatile int32_t r_icp_p_raw, r_icp_t_raw;
static volatile uint8_t r_gzp_ok, r_gzp_stage, r_gzp_data[6];
static volatile uint8_t r_gzp_addr_used;
static volatile uint32_t r_gzp_p_raw;
static volatile int16_t r_gzp_t_raw;
/* r_nf_ok reports the last physical radio transmission completion only;
 * with ACK disabled it never means that a receiver heard the packet. */
static volatile uint8_t r_nf_ok, r_nf_init_ok, r_nf_stage, r_nf_tx_cnt;
static volatile uint16_t r_log_num;
static volatile uint32_t r_log_written;
static volatile uint32_t r_frame_seq;
static volatile uint32_t r_system_ms;
static volatile uint32_t r_runtime_ms;
static volatile uint8_t r_qmi_irq_pending;
/* TIM3 provides a periodic FIFO/status fallback when the PB6 edge is absent. */
static volatile uint8_t r_qmi_poll_due;
/* ICP has no wired interrupt; limit its FIFO service to the 100 ms cadence. */
static volatile uint8_t r_icp_poll_due;
static volatile uint8_t r_qmi_fifo_overflow;
static volatile uint16_t r_qmi_fifo_overflow_count;
static volatile uint16_t r_qmi_late_samples;
static volatile uint16_t r_gzp_missed_count;
/* ICP samples discarded because their timestamp was already outside the
 * retained frame window or still belonged to an SD-owned physical slot.  The
 * V4 layout has no separate ICP counter; the per-frame ICP_FAIL flag carries
 * the diagnostic while this bounded counter keeps the loss explicit for
 * runtime diagnostics and tests. */
static volatile uint16_t r_icp_late_samples;
static volatile uint8_t r_mts_due;
static volatile uint8_t r_nf_due;
static volatile uint8_t r_short_timer_done;
static volatile uint8_t r_sd_full;
static volatile uint8_t r_sd_alloc_pending;
static uint8_t sd_buf[512];
static uint8_t log_meta_buf[512];

/* ST-Link/GDB-readable, RAM-only production diagnostics.  The magic is set
 * when the formal runtime begins, after startup probing, so startup I/O cannot
 * be mistaken for the measured acquisition path. */
volatile Issue3RuntimeDiagnostics r_issue3_diag;

#define FRAME_MAGIC ISSUE3_FRAME_MAGIC_LOG2 /* LOG2 container; V4 current */
#define FRAME_MAGIC_V1 0x4C4F4731u
#define FRAME_VERSION ISSUE3_FRAME_VERSION
#define FRAME_HEADER_SIZE ISSUE3_FRAME_HEADER_SIZE
#define QMI_N ISSUE3_FRAME_QMI_CAPACITY
#define GZP_N ISSUE3_FRAME_GZP_CAPACITY
#define ICP_N ISSUE3_FRAME_ICP_CAPACITY
#define MTS4_N 1
#define QMI_SENSOR_PERIOD_US ((uint32_t)ISSUE3_QMI_SAMPLE_PERIOD_US)
#define QMI_FRAME_RETENTION_MS ((uint32_t)ISSUE3_FRAME_RETENTION_MS)
#define FRAME_QUEUE_N ISSUE3_FRAME_QUEUE_CAPACITY /* oldest retained for derived SD bound */
#define FAT_SCAN_SECTOR_BUDGET 1u /* one bounded background step */
#define GZP_CONVERSION_WAIT_MS 20u /* 0xB4 OSR_P=8x, nominal 19 ms */
#define GZP_CONVERSION_TIMEOUT_MS 100u
#define GZP_RESULT_RETENTION_MS ((uint32_t)ISSUE3_FRAME_RETENTION_MS)
#define QMI_HEALTH_TIMEOUT_MS 500u
#define GZP_HEALTH_TIMEOUT_MS 500u
#define ICP_HEALTH_TIMEOUT_MS 1500u
#define MTS4_HEALTH_TIMEOUT_MS (MTS4_PERIOD_MS + 5000u)
#define MTS4_PERIOD_MS 1800000u
#define NF_HEARTBEAT_PERIOD_MS 1800000u
#define LOG_PROGRESS_TIMEOUT_MS (ISSUE3_FRAME_RETENTION_MS + 5000u)
#define NF_HEARTBEAT_PROTOCOL_VERSION 3U
#define NF_HEARTBEAT_MESSAGE_TYPE 1U
#define NF_STATUS_SD_INIT_OK (1U << 0)
#define NF_STATUS_LOG_ACTIVE (1U << 1)
#define NF_STATUS_SD_FULL (1U << 2)
#define FRAME_QMI_OFF ISSUE3_FRAME_QMI_OFFSET
#define FRAME_GZP_OFF ISSUE3_FRAME_GZP_OFFSET
#define FRAME_ICP_OFF ISSUE3_FRAME_ICP_OFFSET
#define FRAME_MTS_OFF ISSUE3_FRAME_MTS_OFFSET
#define FRAME_DATA_SIZE ISSUE3_FRAME_DATA_SIZE
#define FRAME_CRC_OFF ISSUE3_FRAME_CRC_OFFSET
#define FRAME_SIZE ISSUE3_FRAME_SIZE
#define FRAME_STATUS_QMI_FAIL (1u << 0)
#define FRAME_STATUS_QMI_FIFO_OVERFLOW (1u << 1)
#define FRAME_STATUS_GZP_FAIL (1u << 2)
#define FRAME_STATUS_ICP_FAIL (1u << 3)
#define FRAME_STATUS_MTS_FAIL (1u << 4)
#define FRAME_STATUS_SD_FULL (1u << 5)
#define FRAME_STATUS_GZP_SCHEDULE_OVERFLOW (1u << 6)
#define FRAME_STATUS_QMI_FIFO_CLEANUP (1u << 7)
#define FRAME_STATUS_QMI_REANCHORED (1u << 8)
#define FRAME_STATUS_QMI_LATE_SAMPLE (1u << 9)
/* V4 status bits 10..12 were unused.  They make a QMI stalled-stream
 * watchdog/reconfiguration visible in the persisted frame without changing
 * the frame layout or the meaning of the existing counters.  Bit 10 retains
 * the historical qmi_empty_recovery name for parser compatibility. */
#define FRAME_STATUS_QMI_EMPTY_RECOVERY ISSUE3_QMI_STATUS_EMPTY_RECOVERY
#define FRAME_STATUS_QMI_RECOVERY_OK ISSUE3_QMI_STATUS_RECOVERY_OK
#define FRAME_STATUS_QMI_RECOVERY_FAIL ISSUE3_QMI_STATUS_RECOVERY_FAIL
#define GZP_MEASURE_CMD 0xB4u
#define STATUS_OK 1U
#define STATUS_FAIL 0xFFU
#define STARTUP_DISPLAY_HOLD_MS 10000U

typedef struct {
    uint8_t data[FRAME_SIZE];
    uint32_t start_ms;
    uint8_t qmi_count, gzp_count, icp_count, mts_valid;
    uint16_t qmi_dropped;
    uint16_t gzp_missed;
    uint32_t status;
    uint8_t valid;
} FrameSlot;

static FrameSlot frame_slots[FRAME_QUEUE_N];
static Issue3FrameQueue frame_queue;
static volatile uint32_t frame_status;
static Issue3QmiClock qmi_clock;
/* Runtime state for the valid-zero FIFO watchdog.  This is intentionally a
 * named RAM object so Tiger can inspect the last raw sample and recovery
 * attempt while the device is running. */
static Issue3QmiRecovery qmi_recovery;
/* Read-side decimation phases persist across FIFO batches, frame boundaries,
 * re-anchors and scheduler turns.  Raw sensor reads and clock advancement are
 * never skipped; only the successful sample admitted to the smaller V4 frame
 * is selected by these phases. */
static uint8_t qmi_decimation_phase;
static uint8_t gzp_decimation_phase;
static uint8_t gzp_pending;
static uint8_t gzp_result_ready;
static Issue3GzpResultQueue gzp_results;
static uint32_t gzp_started_ms;
static uint32_t gzp_plan_ms;
static uint8_t mts_pending;
static uint8_t mts_result_ready;
static uint32_t mts_started_ms;
static uint32_t mts_result_ms;
static int16_t mts_result_temp;
static uint32_t next_mts_ms;
static Issue3HeartbeatSchedule nf_heartbeat_schedule;
static Issue3NfBroadcast nf_broadcast;
static uint32_t next_gzp_ms;
static uint8_t log_active;
static uint32_t log_clu, log_lba, total_written;
static uint16_t log_sec_off, log_num;
static uint16_t log_meta_frame_count;
static uint32_t g_data_clusters;
static Issue3FatScan g_fat_scan;
static int g_fat_last_result;
static uint32_t log_next_clu;
static uint8_t log_next_ready;
static Issue3LogPrefetch log_prefetch;
/* The finalized queue slot remains owned by the log writer until its bytes
 * are persisted.  Keeping an index avoids a second full V4 RAM frame. */
static uint8_t log_pending_slot;
static uint16_t log_pending_off;
static uint8_t log_pending_active;
static uint8_t log_metadata_pending;
static uint32_t log_metadata_size;
static uint32_t log_complete_size;
static uint8_t log_link_pending;
static uint8_t log_link_stage;
static uint32_t log_link_cluster, log_link_next, log_link_sector;
static Issue3SectorBuffer log_sector_buffer;

/* Runtime SD transactions are deliberately separate from the synchronous
 * startup/probe helpers above.  CS stays asserted for the complete SD
 * command, while each call to sd_async_step() performs at most one response,
 * token or busy poll, or ISSUE3_SD_STEP_BYTES data bytes.  This preserves the
 * card protocol without allowing a 512-byte hardware-SPI transfer to monopolize
 * the foreground sensor scheduler. */
typedef Issue3SdTransfer SdAsyncTxn;

static SdAsyncTxn sd_async;
/* NF-03 and SD share SCK/MOSI/MISO.  The owner remains held for the whole
 * SD transaction (including token/data/busy phases), or for the complete NF
 * register/send/wake/sleep sequence. */
static Issue3SpiBus shared_spi_bus;
static uint8_t log_sector_write_pending;
static uint8_t log_metadata_stage;
static uint8_t fat_runtime_phase;
static uint32_t fat_runtime_cluster;
static uint32_t fat_runtime_sector;
static uint8_t log_alloc_io;
static uint32_t log_last_progress_ms;
static uint8_t log_write_stalled;

/* Shared with host diagnostics tests; this replaces the former collection of
 * private phase/transaction variables without changing the fixed diagnostic
 * ABI or adding another persistent RAM block. */
static Issue3DiagRuntimeState diag_runtime;

/* A successful register read during startup is not evidence that the
 * sensor kept producing data during the long run.  These timestamps are
 * refreshed only by successful runtime samples and are folded into the
 * heartbeat status immediately before each physical broadcast. */
static uint8_t qmi_sample_seen, gzp_sample_seen, icp_sample_seen,
               mts4_sample_seen;
static uint32_t qmi_last_sample_ms, gzp_last_sample_ms, icp_last_sample_ms,
                mts4_last_sample_ms;

static uint32_t log_persisted_complete_size(void)
{
    uint32_t physical_complete = (total_written / FRAME_SIZE) * FRAME_SIZE;
    return log_complete_size < physical_complete ?
           log_complete_size : physical_complete;
}

static FrameSlot *frame_slot_for(uint32_t timestamp_ms,
                                 Issue3FrameOpenReason *open_reason);
static uint8_t frame_queue_commit_ready(uint32_t now_ms);
static uint8_t frame_add_qmi(uint32_t ts_ms, int16_t ax, int16_t ay, int16_t az,
                             int16_t gx, int16_t gy, int16_t gz);
static uint8_t frame_add_gzp(uint32_t ts_ms, uint32_t pressure_raw,
                             int16_t temperature_raw);
static uint8_t frame_add_icp(uint32_t ts_ms, int32_t p_raw, int32_t t_raw);
static uint8_t frame_add_mts(uint32_t ts_ms, int16_t temp_raw);

#define SYST_CSR (*(volatile uint32_t *)0xE000E010U)
#define SYST_RVR (*(volatile uint32_t *)0xE000E014U)
#define SYST_CVR (*(volatile uint32_t *)0xE000E018U)
#define SYST_CSR_ENABLE   (1U << 0)
#define SYST_CSR_TICKINT  (1U << 1)
#define SYST_CSR_CLKSOURCE (1U << 2)
#define NVIC_ISER (*(volatile uint32_t *)0xE000E100U)
#define NVIC_EXTI4_15_IRQ STM32G030_EXTI4_15_IRQ_BIT
#define NVIC_TIM3_IRQ (1U << 16)
#define EXTI_QMI_PIN STM32G030_QMI_EXTI_PIN
#define EXTI_QMI_EXTICR_INDEX STM32G030_QMI_EXTICR_INDEX
#define EXTI_QMI_EXTICR_SHIFT STM32G030_QMI_EXTICR_SHIFT

#ifndef PCB32_DEVICE_ID0
/* Development default only; deployment builds must override all three. */
#define PCB32_DEVICE_ID0 0x50U
#define PCB32_DEVICE_ID1 0x43U
#define PCB32_DEVICE_ID2 0x42U
#endif

static void systick_init(void)
{
    /* HSI16 is the reset clock; this tick is used only during startup check. */
    SYST_RVR = 16000U - 1U;
    SYST_CVR = 0;
    SYST_CSR = SYST_CSR_CLKSOURCE | SYST_CSR_TICKINT | SYST_CSR_ENABLE;
}

static void systick_stop(void)
{
    SYST_CSR = 0;
}

void SysTick_Handler(void)
{
    r_system_ms++;
}

static inline void cpu_sleep(void)
{
    /* DSB guarantees all timer/EXTI programming is visible before the
     * architectural sleep instruction.  The runtime entry masks interrupts
     * around its final check; short startup waits also benefit from the same
     * ordering. */
    __asm volatile("dsb" ::: "memory");
    __asm volatile("wfi" ::: "memory");
}

static uint32_t runtime_now_ms(void)
{
    uint32_t base_a = r_runtime_ms;
    uint32_t counter = TIM3->CNT;
    uint32_t base_b = r_runtime_ms;
    if (base_a != base_b) {
        base_a = base_b;
        counter = TIM3->CNT;
    }
    return base_a + counter;
}

static int time_reached(uint32_t now, uint32_t deadline)
{
    return (int32_t)(now - deadline) >= 0;
}

static uint8_t issue3_diag_active(void)
{
    return (uint8_t)(r_issue3_diag.magic == ISSUE3_RUNTIME_DIAG_MAGIC &&
                     r_issue3_diag.version == ISSUE3_RUNTIME_DIAG_VERSION);
}

static void issue3_diag_runtime_init(void)
{
    /* .bss has already been cleared by Reset_Handler.  Only the identity is
     * written here; all counters therefore start at zero without a memset or
     * a libc dependency in the freestanding image. */
    r_issue3_diag.magic = ISSUE3_RUNTIME_DIAG_MAGIC;
    r_issue3_diag.version = ISSUE3_RUNTIME_DIAG_VERSION;
    diag_runtime.sd_phase = 0xffU;
}

static void issue3_diag_observe_depths(void)
{
    if (!issue3_diag_active()) return;
    if (frame_queue.count > r_issue3_diag.frame_queue_max_depth)
        r_issue3_diag.frame_queue_max_depth = frame_queue.count;
    if (gzp_results.count > r_issue3_diag.gzp_queue_max_depth)
        r_issue3_diag.gzp_queue_max_depth = gzp_results.count;
}

static void issue3_diag_note_drop(uint8_t sensor,
                                  Issue3FrameOpenReason reason)
{
    if (!issue3_diag_active()) return;
    issue3_diag_note_frame_drop(&r_issue3_diag, sensor, reason);
}

static void issue3_diag_note_old_icp(uint32_t first_ms, uint32_t count)
{
    if (!issue3_diag_active()) return;
    for (uint32_t i = 0U; i < count; i++)
        issue3_diag_note_drop(
            ISSUE3_DIAG_SENSOR_ICP,
            issue3_frame_queue_timestamp_reason(
                &frame_queue, first_ms + i * 500U));
}

static void issue3_diag_sd_transaction_begin(uint8_t op, uint32_t now_ms)
{
    if (!issue3_diag_active()) return;
    issue3_diag_runtime_sd_begin(&r_issue3_diag, &diag_runtime, op, now_ms);
}

static void issue3_diag_sd_transaction_finish(uint32_t now_ms)
{
    if (!issue3_diag_active()) return;
    issue3_diag_runtime_sd_finish(&r_issue3_diag, &diag_runtime, now_ms);
}

static void issue3_diag_operation_begin(volatile Issue3DiagStage *stage,
                                        uint8_t *active, uint32_t *start_ms)
{
    if (!issue3_diag_active()) return;
    issue3_diag_runtime_operation_begin(&r_issue3_diag, stage, active,
                                        start_ms, runtime_now_ms());
}

static void issue3_diag_operation_finish(volatile Issue3DiagStage *stage,
                                         uint8_t *active, uint32_t start_ms,
                                         uint32_t now_ms)
{
    if (!issue3_diag_active()) return;
    issue3_diag_runtime_operation_finish(&r_issue3_diag, stage, active,
                                         start_ms, now_ms);
}

static void issue3_diag_sector_complete(uint32_t now_ms)
{
    if (!issue3_diag_active()) return;
    issue3_diag_runtime_sector_complete(
        &r_issue3_diag, &diag_runtime, now_ms, total_written,
        total_written / FRAME_SIZE);
}

static void gzp_note_missed(uint32_t count)
{
    if ((uint32_t)r_gzp_missed_count + count > 0xFFFFU) {
        r_gzp_missed_count = 0xFFFFU;
        frame_status |= FRAME_STATUS_GZP_SCHEDULE_OVERFLOW;
    } else {
        r_gzp_missed_count = (uint16_t)(r_gzp_missed_count + count);
    }
}

typedef struct {
    uint16_t milliseconds;
    uint32_t compare;
    uint8_t armed;
} ShortWaitContext;

static void runtime_irq_disable(void *ctx);
static void runtime_irq_enable(void *ctx);

static uint8_t short_wait_ready(void *ctx)
{
    (void)ctx;
    return r_short_timer_done;
}

static uint8_t short_wait_pending(void *ctx)
{
    (void)ctx;
    uint32_t status = TIM3->SR;
    if (status & TIM_SR_CC1IF) {
        /* The start callback cleared the previous interval's flag.  A CC1IF
         * seen here is therefore a new compare event (possibly arriving in
         * the final check/WFI window); make it serviceable without clearing
         * the pending source. */
        TIM3->DIER |= TIM_DIER_CC1IE;
        return 1U;
    }
    return (status & TIM_SR_UIF) != 0U;
}

static void short_wait_start(void *ctx)
{
    ShortWaitContext *wait = (ShortWaitContext *)ctx;
    uint32_t duration = wait->milliseconds;

    /* This callback runs with PRIMASK set.  Disable the old compare source,
     * remove only the stale CC1 flag, and clear the completion state before
     * taking the CNT sample for this interval. */
    TIM3->DIER &= ~TIM_DIER_CC1IE;
    TIM3->SR &= ~TIM_SR_CC1IF;
    r_short_timer_done = 0U;
    wait->armed = 0U;

    /* CNT can advance while the MMIO writes above are in flight.  If it has
     * already crossed the requested interval, discard that candidate and
     * establish a fresh target from the newer sample.  The second CNT check
     * closes the same boundary immediately before CC1IE is enabled. */
    for (;;) {
        uint32_t start = TIM3->CNT % ISSUE3_SHORT_TIMER_PERIOD_MS;
        uint32_t target = (start + duration) % ISSUE3_SHORT_TIMER_PERIOD_MS;
        TIM3->CCR1 = target;
        uint32_t after_program = TIM3->CNT % ISSUE3_SHORT_TIMER_PERIOD_MS;
        if (!issue3_short_timer_target(start, after_program,
                                       (uint16_t)duration, &target)) {
            TIM3->SR &= ~TIM_SR_CC1IF;
            continue;
        }

        /* Any flag raised before the new compare target was reached belongs
         * to the previous CCR1 value.  It is safe to clear it only while the
         * target is still in the future. */
        TIM3->SR &= ~TIM_SR_CC1IF;
        uint32_t confirmed = TIM3->CNT % ISSUE3_SHORT_TIMER_PERIOD_MS;
        if (!issue3_short_timer_target(start, confirmed,
                                       (uint16_t)duration, &target)) {
            TIM3->SR &= ~TIM_SR_CC1IF;
            continue;
        }

        wait->compare = target;
        wait->armed = 1U;
        TIM3->DIER |= TIM_DIER_CC1IE;
        return;
    }
}

static void short_wait_arm(void *ctx)
{
    ShortWaitContext *wait = (ShortWaitContext *)ctx;
    /* The interval was already established atomically by short_wait_start.
     * A spurious update wake must not restart it and extend the delay. */
    if (!wait->armed) {
        wait->compare = (TIM3->CNT + wait->milliseconds) %
                        ISSUE3_SHORT_TIMER_PERIOD_MS;
        TIM3->CCR1 = wait->compare;
        wait->armed = 1U;
    }
    TIM3->DIER |= TIM_DIER_CC1IE;
}

static void short_wait_wfi(void *ctx)
{
    (void)ctx;
    cpu_sleep();
}

static const Issue3AtomicWaitOps short_wait_ops = {
    runtime_irq_disable,
    runtime_irq_enable,
    short_wait_ready,
    short_wait_pending,
    short_wait_arm,
    0,
    short_wait_wfi,
    short_wait_start
};
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

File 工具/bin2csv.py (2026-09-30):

#!/usr/bin/env python3
"""Convert PCB32 binary logs to CSV with fail-closed frame parsing.

V1 is the legacy fixed 1722-byte format (LOG1 magic, no per-sample time).
V2/V3 are the historical 674-byte LOG2 formats.  V4 is the current 368-byte
LOG2 format with post-read QMI/GZP half-rate capacities.  Frames are consumed
strictly at their boundaries; payload bytes are never searched for a
replacement magic.
"""
import binascii
import csv
import os
import struct
import sys

FRAME_MAGIC_V1 = 0x4C4F4731
FRAME_MAGIC_V2 = 0x4C4F4732
FRAME_VERSION_V2 = 2
FRAME_VERSION_V3 = 3
FRAME_VERSION_V4 = 4
FRAME_V1_SIZE = 1722
FRAME_V2_DATA_SIZE = 670
FRAME_V2_SIZE = 674
FRAME_V4_DATA_SIZE = 364
FRAME_V4_SIZE = 368
V2_HEADER_SIZE = 32
QMI_SLOTS_V2 = 32
GZP_SLOTS_V2 = 10
ICP_SLOTS_V2 = 2
QMI_SLOTS_V4 = 16
GZP_SLOTS_V4 = 5
ICP_SLOTS_V4 = 2
CRC_OFFSET_V2 = FRAME_V2_DATA_SIZE
CRC_OFFSET_V4 = FRAME_V4_DATA_SIZE

# V4 reuses the existing 32-bit status field.  Bits 10..12 are deliberately
# outside the historical flags and identify a persisted QMI empty-stream
# recovery attempt; older V1/V2/V3 frames always decode these as zero.
STATUS_QMI_EMPTY_RECOVERY = 1 << 10
STATUS_QMI_RECOVERY_OK = 1 << 11
STATUS_QMI_RECOVERY_FAIL = 1 << 12


def qmi_recovery_flags(status):
    return {
        'qmi_empty_recovery': int(bool(status & STATUS_QMI_EMPTY_RECOVERY)),
        'qmi_recovery_ok': int(bool(status & STATUS_QMI_RECOVERY_OK)),
        'qmi_recovery_failed': int(bool(status & STATUS_QMI_RECOVERY_FAIL)),
    }


def s16(buf, off):
    return struct.unpack_from('<h', buf, off)[0]


def u16(buf, off):
    return struct.unpack_from('<H', buf, off)[0]


def u32(buf, off):
    return struct.unpack_from('<I', buf, off)[0]


def s20(buf, off):
    value = buf[off] | (buf[off + 1] << 8) | (buf[off + 2] << 16)
    value &= 0xFFFFF
    if value & 0x80000:
        value -= 0x100000
    return value


def u24(buf, off):
    return buf[off] | (buf[off + 1] << 8) | (buf[off + 2] << 16)


def _need(buf, off, size, what):
    if off < 0 or off + size > len(buf):
        raise ValueError(f"偏移 {off} 的 {what} 截断：需要 {size} 字节")


def is_v2(buf, off):
    return off + 4 <= len(buf) and u32(buf, off) == FRAME_MAGIC_V2


def _parse_log2(buf, off, version, frame_size, crc_offset,
                qmi_slots, gzp_slots, icp_slots):
    _need(buf, off, V2_HEADER_SIZE, "V2 帧头")
    if u32(buf, off) != FRAME_MAGIC_V2:
        raise ValueError(f"偏移 {off} 不是 LOG2 magic")
    actual_version = u16(buf, off + 4)
    if actual_version != version:
        raise ValueError(f"偏移 {off} 的版本不匹配：期望 {version}，实际 {actual_version}")
    if u16(buf, off + 6) != V2_HEADER_SIZE:
        raise ValueError(f"偏移 {off} 的 LOG2 header_size 错误")
    _need(buf, off, frame_size, f"V{version} 帧")

    expected_crc = u32(buf, off + crc_offset)
    actual_crc = binascii.crc32(buf[off:off + crc_offset]) & 0xFFFFFFFF
    if expected_crc != actual_crc:
        raise ValueError(f"偏移 {off} 的 V{version} CRC32 错误：期望 0x{expected_crc:08x}，实际 0x{actual_crc:08x}")

    qmi_count, gzp_count, icp_count, mts_valid = struct.unpack_from('<4B', buf, off + 16)
    if qmi_count > qmi_slots:
        raise ValueError(f"偏移 {off} 的 qmi_count 超过容量")
    if gzp_count > gzp_slots:
        raise ValueError(f"偏移 {off} 的 gzp_count 超过容量")
    if icp_count > icp_slots:
        raise ValueError(f"偏移 {off} 的 icp_count 超过容量")
    if mts_valid > 1:
        raise ValueError(f"偏移 {off} 的 mts_valid 非法")

    frame = {
        'version': version, 'seq': u32(buf, off + 8),
        'frame_start_ms': u32(buf, off + 12), 'status': u32(buf, off + 20),
        'qmi_dropped': u16(buf, off + 24),
        'qmi_fifo_overflows': u16(buf, off + 26),
        'qmi_reanchors': u16(buf, off + 28) if version in
                         (FRAME_VERSION_V3, FRAME_VERSION_V4) else 0,
        'gzp_missed': u16(buf, off + 30),
        'qmi': [], 'gzp': [], 'icp': [], 'mts4': None,
    }
    frame.update(qmi_recovery_flags(frame['status']))
    p = off + V2_HEADER_SIZE
    for _ in range(qmi_count):
        frame['qmi'].append((u32(buf, p),) + struct.unpack_from('<6h', buf, p + 4))
        p += 16
    p = off + V2_HEADER_SIZE + qmi_slots * 16
    for _ in range(gzp_count):
        frame['gzp'].append((u32(buf, p), u24(buf, p + 4), s16(buf, p + 7)))
        p += 10
    p = off + V2_HEADER_SIZE + qmi_slots * 16 + gzp_slots * 10
    for _ in range(icp_count):
        frame['icp'].append((u32(buf, p), s20(buf, p + 4), s20(buf, p + 7)))
        p += 10
    if mts_valid:
        p = off + V2_HEADER_SIZE + qmi_slots * 16 + gzp_slots * 10 + icp_slots * 10
        frame['mts4'] = (u32(buf, p), s16(buf, p + 4))
    return frame


def parse_v2(buf, off, version=None):
    if version is None:
        _need(buf, off, 6, "LOG2 版本")
        version = u16(buf, off + 4)
    if version not in (FRAME_VERSION_V2, FRAME_VERSION_V3):
        raise ValueError(f"偏移 {off} 的未知 V2/V3 版本 {version}")
    return _parse_log2(buf, off, version, FRAME_V2_SIZE, CRC_OFFSET_V2,
                       QMI_SLOTS_V2, GZP_SLOTS_V2, ICP_SLOTS_V2)


def parse_v4(buf, off):
    return _parse_log2(buf, off, FRAME_VERSION_V4, FRAME_V4_SIZE,
                       CRC_OFFSET_V4, QMI_SLOTS_V4, GZP_SLOTS_V4,
                       ICP_SLOTS_V4)


def parse_v1(buf, off):
    _need(buf, off, FRAME_V1_SIZE, "V1 帧")
    if u32(buf, off) != FRAME_MAGIC_V1:
        raise ValueError(f"偏移 {off} 不是 V1 magic")
    frame = {
        'version': 1, 'seq': u32(buf, off + 4),
        'frame_start_ms': u32(buf, off + 8), 'status': 0, 'qmi_dropped': 0,
        'qmi_fifo_overflows': 0,
        'gzp_missed': 0, 'qmi_reanchors': 0,
        'qmi': [], 'gzp': [], 'icp': [], 'mts4': None,
    }
    frame.update(qmi_recovery_flags(frame['status']))
    p = off + 16
    for i in range(112):
        frame['qmi'].append((None,) + struct.unpack_from('<6h', buf, p + i * 12))
    p += 112 * 12
    for i in range(50):
        frame['gzp'].append((None, u24(buf, p + i * 6), s16(buf, p + i * 6 + 3)))
    p += 50 * 6
    for i in range(10):
        frame['icp'].append((None, s20(buf, p + i * 6), s20(buf, p + i * 6 + 3)))
    frame['mts4'] = (None, s16(buf, off + 1720))
    return frame
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

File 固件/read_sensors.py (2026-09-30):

#!/usr/bin/env python3
import os
from pathlib import Path
import signal
import subprocess
import time


FIRMWARE_DIR = Path(__file__).resolve().parent
FIRMWARE_ELF = FIRMWARE_DIR / '编译输出' / 'firmware.elf'

subprocess.run(["killall", "openocd", "gdb-multiarch", "st-util"], capture_output=True)
time.sleep(1)

ocd = subprocess.Popen(["openocd", "-f", str(FIRMWARE_DIR / "openocd.cfg")],
                       stdout=subprocess.DEVNULL, stderr=subprocess.DEVNULL)
time.sleep(2)

gdb = subprocess.Popen(
    ['gdb-multiarch', str(FIRMWARE_ELF)],
    stdin=subprocess.PIPE, stdout=subprocess.PIPE, stderr=subprocess.STDOUT)
def cmd(s):
    gdb.stdin.write((s + '\n').encode())
    gdb.stdin.flush()
    time.sleep(0.3)

def read_until_prompt(timeout=2):
    import select
    data = b''
    deadline = time.time() + timeout
    while time.time() < deadline:
        ready, _, _ = select.select([gdb.stdout], [], [], 0.1)
        if ready:
            chunk = gdb.stdout.read1(4096) if hasattr(gdb.stdout, 'read1') else os.read(gdb.stdout.fileno(), 4096)
            data += chunk
            if b'(gdb)' in data:
                break
    return data.decode(errors='replace')

cmd('set architecture arm')
cmd('target remote :3333')
cmd('set pagination off')
read_until_prompt()

# Resume MCU and let it run for a while
cmd('continue')
time.sleep(4)  # Let sensors initialize and collect data

# Send Ctrl-C to stop
os.kill(gdb.pid, signal.SIGINT)
time.sleep(1)
read_until_prompt()

# Now read the variables
cmd('x/1xw 0x20000010')  # magic
cmd('x/3xh 0x20000000')  # ax, ay, az
cmd('x/3xh 0x20000006')  # gx, gy, gz
cmd('x/1xh 0x20000016')  # mts4_temp
cmd('x/3xb 0x20000018')  # qmi_ok, mts4_ok, icp_ok
cmd('x/1xw 0x4002101C')  # RCC_APBENR1
cmd('x/1xw 0x48000400')  # GPIOA_MODER
time.sleep(1)
cmd('quit')

out = gdb.stdout.read().decode(errors='replace')
for line in out.splitlines():
    line = line.strip().replace('(gdb) ', '')
    if '0x2' in line or '0x4' in line:
        print(line)

gdb.wait()
ocd.terminate()
